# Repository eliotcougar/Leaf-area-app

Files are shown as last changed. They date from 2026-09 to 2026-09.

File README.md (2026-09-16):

# Leaf Area

Measure the projected leaf area inside a **6 cm² LI-6800 chamber opening** using an Android phone and a printed calibration mask.

The app uses markers around the opening to correct perspective and convert pixels to real area. Only leaf tissue inside the circle is counted. Processing works entirely on the device, without an internet connection or account.

## What you need

- An Android phone running Android 8.0 or newer.
- The [V2 cutout PDF](app/src/main/assets/LI6800-6cm2-marker-cutout-v2.pdf), printed on A4 paper.
- A flat, matte white backing, or a blue mat for contrasting with the leaf.

For a stiffer mask, attach the printout to a 3D-printed backing made from the [0.4 mm STEP model](app/src/main/assets/LI6800-6cm2-mask-v2-0.4mm.step). Both files can also be exported from the app’s menu.

## Measure a leaf

1. **Print at Actual size / 100%.** Disable “Fit to page” and check the printed 50 mm ruler. Cut out the mask and its circular opening, leaving the square markers intact.
2. Place the leaf flat on the backing with the mask on top. Keep the leaf and markers as close to the same plane as possible.
3. Open the camera and hold the phone nearly overhead. Keep the complete opening and at least four markers visible, distributed around the circle. Use even lighting and avoid glare.
4. Switch to **Calibration** to inspect the highlighted tissue. Select the matching backing color and adjust sensitivity until the selection follows the leaf. The area updates live in both views.
5. **Freeze** to inspect a reading, or tap the round **Save** button between Camera and Calibration to store it with an optional sample ID.

If markers disappear, the app keeps the last calibrated reading and labels it **Last reading**. Measurements resume when tracking returns. Saving a held reading stores its original calibrated image.

The screen stays awake during live measurement in both Camera and Calibration. Normal screen timeout resumes when you freeze the measurement or leave the app.

The camera button opens a list of available cameras and lenses. Your camera choice, matte color, and leaf sensitivity are remembered. The white or blue circle beside the flashlight shows the selected matte; change it in **Calibration**. Entries marked **automatic** let the phone choose the lens; choose an individual lens when you want to keep it fixed.

Use the flashlight button beside the camera button to toggle the selected camera’s light. It stays on in circle preview and turns off when you freeze or change cameras. Cameras without a flash show a disabled button.

For the LI-6800, enter the measured area in **cm²** as **S** under **Constants → Gas Exchange**. Keep the instrument’s chamber aperture set to 6 cm², and ensure the measured leaf region is the region enclosed by the chamber.

## Save and export

Open **Saved** to share a measurement as a ZIP containing:

- A CSV with the measured area.
- The source image, corrected circle image, and highlighted selection.
- A tissue mask and calibration metadata.

You can also measure an existing image using **Open photo**. Saved measurements stay on your device; export important records before uninstalling the app or clearing its data.

## Measurement limits

This app measures **projected area**, not the surface area of a curled leaf. Print scaling, a warped mask, lens distortion, uneven lighting, and shadows can affect the result. Inspect the selection before saving and check accuracy against known areas before using it in an experiment.

Detached dark shadows near the rim are filtered out, but shadows touching the leaf may still be counted. Very thin, gray tissue at the rim may be excluded. A physical measurement accuracy specification has not yet been established.

## Build from source

Open the project in Android Studio, using **JDK 21**, **Android SDK 37**, and **Build Tools 37.0.0**. Let Gradle sync, then run the app on a device or emulator.

Alternatively, with the JDK and Android SDK configured:

```sh
./gradlew :app:assembleDebug
```

On Windows, use `gradlew.bat` instead of `./gradlew`. The APK is written to `app/build/outputs/apk/debug/`.

For an optimized build, use `:app:assembleRelease`. Release builds enable code and resource shrinking; configure your own release signing key before distributing a build.

Built with Kotlin, Jetpack Compose, CameraX, and OpenCV. The template and mask generators are in [`tools/`](tools/).

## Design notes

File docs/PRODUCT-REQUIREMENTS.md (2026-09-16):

# LI-6800 product requirements

Read these requirements before changing measurements, templates, cameras, or
the measurement UI. They reflect the decisions through version 0.4.6; update
them when the product requirements change.

They take precedence over superseded proposals in
[MEASUREMENT-DESIGN.md](MEASUREMENT-DESIGN.md), including its proposed
mm²/coverage display and marker-loss presentation. The design document remains
the source for original-PDF findings and scientific validation requirements.
Release evidence belongs in versioned validation reports; the snapshot at this
revision is [VALIDATION-v046.md](VALIDATION-v046.md).

## Measurement and template

- Preserve `calibration_pad_pro.pdf` and `LI-6800-mask.pdf` unchanged. Print
  templates at Actual size / 100%, without resizing.
- Measure leaf tissue only within the 6.000 cm² (600 mm²) circular opening.
  Keep measured original-PDF geometry separate from that intended geometry;
  never silently rescale measurements to hide a mismatch.
- Require at least four markers around the opening for live calibration.
  Only V2 is calibrated; V1 support was removed in 0.4.0. Never reuse marker IDs
  across scales.
- The V2 PDF/STEP uses ten 8 mm markers, IDs 20-29, with two rear-center markers
  and forward side wings. Preserve the 111 × 68 × 0.4 mm backing, central front
  R20 arc, and 6 cm² opening.
- Use automatic segmentation with backing and sensitivity controls; the user
  excluded an add/erase workflow. Remember leaf sensitivity and selected matte
  across app restarts; default to white when no valid matte preference exists.
- Remove detached low-color rim shadows without shrinking the aperture.
  Preserve interior tissue and colored leaf tips.
- On marker loss, retain the last valid area, source, and timestamp with an
  explicit held-reading label; do not present a stale result as live.
- Keep demo workflows out of production and synthetic images in
  `androidTest/assets`, not `main/assets`. The menu exports PDF and STEP offline.

## Measurement screen

Keep the screen fixed and non-scrollable. Its two live display modes are a
full-screen camera and a square circle preview with sensitivity below. Both show
area at the top, in cm², without a mm²/coverage row.

The bottom row is Camera, a circular Save icon, and Calibration. Save is available
in both modes; do not duplicate it in the top overlay. Keep the same camera
session across display and tracking changes.

In Camera view, show the selected matte as a white or blue circle beside the
flashlight, matching its circle size. It is a status indicator; matte selection
remains in Calibration. Give the indicator an accessible selected-matte label.

While `InputMode.CAMERA` is active, keep the activity window awake in either
display mode, including marker loss. Clear `FLAG_KEEP_SCREEN_ON` when live mode
ends and on disposal; allow normal background timeout. Do not use a CPU wake lock.

## Camera selection and torch

The camera button lists exposed cameras/physical lenses and marks the remembered
selection. Distinguish automatic logical cameras from fixed physical lenses.
Keep failed choices selectable for retry, ignore error callbacks from old
sessions, and do not silently fall back on binding or runtime failure. Changing
cameras clears the previous calibration. Keep autofocus.

With the current CameraX 1.6.1 integration, preserve
`CameraChoice.configureOutputs` applying Camera2Interop physical IDs to both
Preview and ImageAnalysis builders. A selector's physical ID alone does not
establish the selected output. Verify resolved session/output IDs and
camera-service streams, not just the remembered picker key.

The flashlight toggle beside the picker uses the bound CameraX camera and
observed torch state. Disable it when flash is unavailable, keep torch on across
display changes, and turn it off when unbinding. Torch errors must not switch
cameras.

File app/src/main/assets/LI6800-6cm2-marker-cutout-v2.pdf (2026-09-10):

# Leaf area / 6 cm2

PRINT AT ACTUAL SIZE (100%) ON A4. Disable Fit to page.

Two identical cutouts. Cut on the outer line and remove the inner circle.

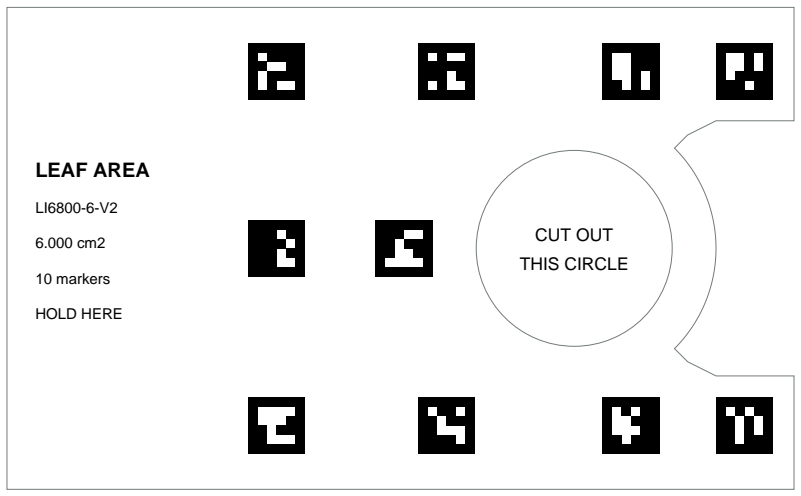
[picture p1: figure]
LEAF AREA; 10 markers; HOLD HERE; CUT OUT THIS CIRCLE
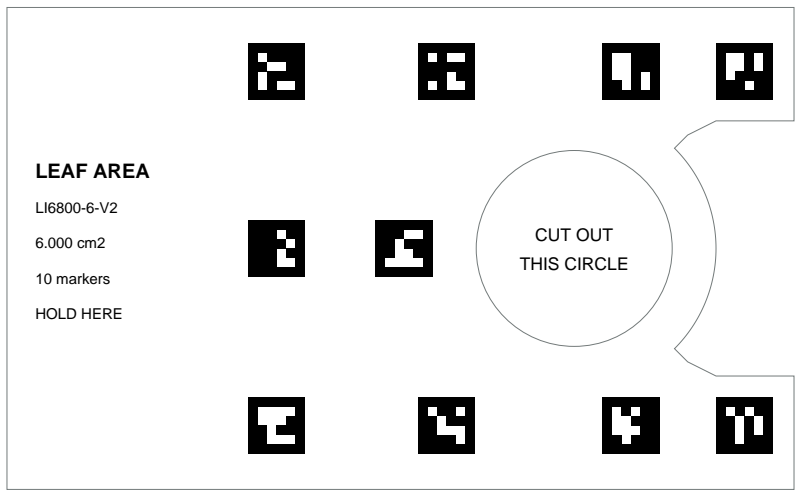
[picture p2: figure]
LEAF AREA; 10 markers; HOLD HERE; CUT OUT THIS CIRCLE

Check this line measures exactly 50 mm after printing

Place the leaf flat on a white backing, with this cutout on top.
Keep four or more well-spread markers visible. Use app 0.2.0 or newer.
Only leaf tissue in the circle is measured. Check the colored overlay before saving. Opening diameter: 27.6395 mm. The front tip retains the original 20 mm radius. External imaging aid. Keep the same leaf region registered for LI-6800 measurements.

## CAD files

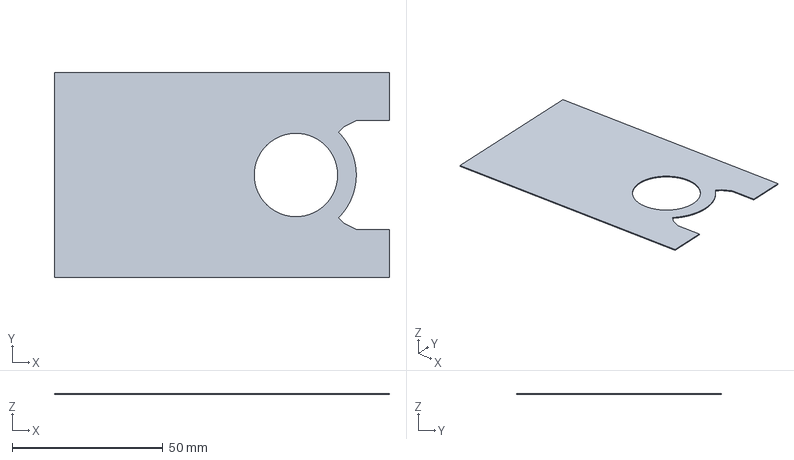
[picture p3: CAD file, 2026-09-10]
app/src/main/assets/LI6800-6cm2-mask-v2-0.4mm.step
111.0 x 68.0 x 0.4 mm

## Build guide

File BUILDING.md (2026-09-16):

# Android build environment on this PC

The root contains the LI-6800 Leaf Area app. Use `tools/build.ps1` to
build it; see `README.md` and `docs/VALIDATION-v046.md` for current behavior and checks.
The preparation results below remain a historical record of toolchain setup.

Inspected on 2026-09-10 at `E:\programming\li6800-area-app`.
The folder initially contained only the two reference PDFs and had no Git repository,
Android source, Gradle files, or app specification.

## Reference material

Both files have one A4 portrait page (595.28 x 841.89 PDF points).

| Input | Observed contents | SHA-256 |
| --- | --- | --- |
| `calibration_pad_pro.pdf` | Four PETIOLE PRO checkerboard calibration pads, numbers 5-8, with square markers and dashed cut outlines. | `9058EB1641443EC6F49095DF27F2E80B6DDB1639FD3E49665A59577CAB9C2116` |
| `LI-6800-mask.pdf` | Four mask outlines with circular openings near rounded ends. No extractable text or printed dimensions. | `8DBF324A2F4886218DC7214D2A3B5B6DE25125E46D51D00323A2044D38FB05D7` |

The user subsequently confirmed that the PDFs are true scale and must be printed
at Actual size / 100%, with no printer scaling. The application target is a 6 cm²
circle. Direct vector inspection found a small discrepancy in the original mask
drawing; see `docs/MEASUREMENT-DESIGN.md` and `docs/reference-geometry.json` for the
separate source dimensions and intended target. The original PDFs are unchanged.
The added real-world photo and proposed marker/measurement workflow are documented
in that design note. Legacy marker families/IDs have not been decoded.

## Installed tools and borrowed inputs

| Item | Verified local location/version |
| --- | --- |
| Java | `C:\Program Files\Android\Android Studio\jbr`, JetBrains JDK 21.0.10 |
| Android SDK | `C:\Users\eliot\AppData\Local\Android\Sdk` |
| SDK platforms | `platforms\android-36.1`, `platforms\android-37.0` (37 metadata has PreviewSdkInt=0) |
| Build tools | `build-tools\36.0.0`, `36.1.0`, `37.0.0` |
| ADB | SDK `platform-tools\adb.exe` |
| Emulator | SDK `emulator\emulator.exe`; no emulator launched for preparation |
| HTTPS curl | `C:\Users\eliot\AppData\Local\Microsoft\WinGet\Links\curl.exe`, curl-mingw 8.21.0 with LibreSSL 4.3.2 |
| Shared Gradle cache | `E:\programming\v2rayng\.gradle-user-home`, with Gradle 9.5.1 and 9.6.0 distributions |

The SDK's `cmdline-tools` directory is absent. Already installed SDK packages can
still build apps. If additional packages are required, use Android Studio's SDK
Manager or explicitly install command-line tools; do not assume `sdkmanager` is on PATH.

The Gradle wrapper was copied byte-for-byte from
`E:\programming\v2rayng\.worktrees\agp-modernization\V2rayNG`
(inspected HEAD `5f4949c56`). It pins Gradle 9.6.0 with its existing distribution
SHA-256. The smoke fixture uses the locally inspected AGP 9.4.0 / Kotlin 2.4.10
combination, compile/target SDK 37, build tools 37.0.0, and Java bytecode target 17.
These are local build inputs, not a claim about the latest available releases.

AGP in this fixture supplies built-in Kotlin. Its buildscript overrides the Kotlin
plugin dependency to the inspected 2.4.10 version. Do not additionally apply
`org.jetbrains.kotlin.android`. The root app uses the matching Compose compiler
plugin 2.4.10; the original smoke fixture does not use Compose.

Only the standard wrapper files were copied. The SDK/JDK and shared Gradle user
cache are referenced in place. Project caches use separate subdirectories here,
keyed by project path. Android user home and debug signing material remain local.
No v2rayNG VPN code, Go/NDK tooling, native AARs, product flavors, or signing keys
are needed by this Kotlin build fixture.

## Commands

Run from this folder in PowerShell. In Codex, every Gradle/build/test invocation
must use `sandbox_permissions: "require_escalated"`; do not use Windows UAC `RunAs`.
The script itself does not request elevation.

```powershell
# Compile Kotlin, process Android resources, dex, and package a debug smoke APK.
.\tools\smoke-build.ps1 -Offline

# Allow dependency downloads if an offline cache entry is unavailable.
.\tools\smoke-build.ps1

# Build the actual app:
.\tools\build.ps1
.\tools\build.ps1 -Tasks @(':app:assembleDebug', ':app:lintDebug')

# Signed, minified app release (same preserved signing identity):
.\tools\build.ps1 -Tasks @(':app:assembleRelease', ':app:lintRelease')
```

The smoke project lives under `tools\smoke-project`; its artifact is
`tools\smoke-project\app\build\outputs\apk\debug\app-debug.apk`.
It uses a separate `local.li6800.toolchainsmoke` package and provisional minSdk 24.
It is not the LI-6800 app. Running `tools/build.ps1` against the root builds
`app/build/outputs/apk/debug/app-debug.apk`, package `org.li6800.area`.

`tools/build.ps1` accepts `-ProjectPath`, `-JavaHome`, `-AndroidSdk`, and
`-GradleUserHome` overrides. It sets JAVA_HOME, ANDROID_HOME, ANDROID_SDK_ROOT,
ANDROID_USER_HOME, GRADLE_USER_HOME, and PATH together, restores them afterward,
uses `--no-daemon` and `--project-cache-dir`, writes timestamped logs under
`.build-logs`, and throws on Gradle failure. `--no-daemon` can still create a
single-use Gradle daemon that exits when the build finishes.

Use PowerShell array syntax for multiple tasks. Do not concatenate optional flags
into a command string or pass an empty ABI flag: this previously produced a stray
`-` task in another project on this PC.

## Machine-specific failure prevention

- A fresh project may have no ignored `local.properties`. Set both SDK environment
  variables in the same shell invocation as Gradle. A stale `sdk.dir` in an existing
  `local.properties` overrides them; inspect it before building.
- Sandbox cache/temp/subprocess failures can look like broken dependencies or
  compiler errors. Use the required unsandboxed execution from the beginning.
- Use the explicit curl-mingw path for HTTPS downloads; the Windows system curl is
  known to fail here. The installed alternative currently identifies LibreSSL,
  rather than Schannel. Never use `--insecure` as a workaround.
- Share dependency/distribution caches, not project state. Do not delete v2rayNG
  caches, modify its worktrees, or stop shared Gradle daemons during troubleshooting.
- Give builds time; inspect the current log and process command line before
  assuming a quiet process is stuck.
- Run at most one emulator on this PC. Inspect ADB devices and emulator/QEMU
  processes before launch, and establish ownership before stopping any existing one.
- The helper creates a project-local Android user home for future debug signing.
  Preserve the resulting key. For an update APK, compare signer certificate SHA-256
  with the previous artifact/device. Never silently switch to a v2rayNG or user key.

## Verification boundary

See the preparation result below for actual command outcomes. The smoke fixture
only checks the Android build toolchain. Runtime, camera permissions, calibration,
measurement accuracy, Compose dependencies, release signing, and device compatibility
are separate checks. Current app verification is recorded in `docs/VALIDATION-v046.md`.

Borrowed instruction sources: `E:\programming\v2rayng\AGENTS.md`,
`E:\programming\v2rayng\.tools\build-v2rayng-release-verify.ps1`, and the inspected
AGP modernization worktree's wrapper and Gradle configuration.

## Preparation result (2026-09-10)

- `tools/smoke-build.ps1 -Offline`: **passed**, 39 seconds, 34 tasks executed.
  Kotlin compilation, Android resource processing, dexing, and debug APK packaging
  succeeded without dependency downloads.
- Build log: `.build-logs\gradle-20260910-133039-740-5632.log`.
- Smoke APK: 933,835 bytes; SHA-256
  `595E7CBEDE38C37771CAE2DF938ED27A4A33CC92F8B36116C6D93E998524A9F6`.
- `apksigner verify --print-certs`: passed. Debug certificate SHA-256
  `597b4d2452fab4dec76811d4a4c6203ddd732ea8605ad05a1ff54581209766a1`.
  The new key is `.android-user-home\debug.keystore`; keep it ignored and preserve it.
- Both PowerShell scripts parsed successfully. All four copied wrapper files match
  the source SHA-256. Both PDF hashes still match their initial values.
- Final host process inspection found no Java/Gradle, Git, or emulator/QEMU process.
  The ADB device list was empty. The ADB server started by the inventory check is
  intentionally left available on port 5037; no APK was installed.
- **Not run during preparation:** emulator/physical-device execution, Compose
  compilation, camera or measurement validation, and production release signing.

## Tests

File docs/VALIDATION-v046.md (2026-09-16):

# Version 0.4.6 — remember and display the selected matte

Validated 2026-09-16.

The selected matte is saved in measurement preferences and restored on app
startup, with white as the fallback for missing or invalid values. The camera
screen displays a white or blue 40 dp circle beside the flashlight, inside a
48 dp layout box. It has an accessible selected-matte label; selection remains
in Calibration.

## Checks

- Signed release assembly and lint passed in 1m 40s; zero lint errors,
  30 warnings. Log: `.build-logs/gradle-20260916-124952-738-22916.log`.
- Installed the minified release on Pixel_6a API 33 x86_64. The initial matte
  without a saved preference was white.
- Selected blue in Calibration, returned to Camera, force-stopped the app and
  relaunched it: the matte and indicator remained blue. Repeated for white,
  with the same successful result.
- UI-tree checks confirmed the selected-matte labels and non-clickable indicator.
  Visual inspection of both restarted screenshots confirmed matching flashlight
  circle size and no clipping or overlap.
- Evidence: `.build-logs/qa/matte-v046.txt`, `v046-restarted-blue.png`,
  `v046-restarted-white.png`, and their XML snapshots.
- Runtime logs showed one camera binding per process, with no extra binding
  when changing matte or display mode, and no LeafArea or AndroidRuntime errors.
  Log: `.build-logs/qa/runtime-v046.txt`.
- No full regression suite was rerun or new repository tests added for this
  small settings/UI change. Physical-device behavior was not tested.

## Release artifact

`output/apk/LI6800-Area-0.4.6-release-universal.apk`, versionCode 10,
149,606,041 bytes; minified, resource-shrunk, non-debuggable, four ABIs.

- SHA-256: `edebd48ff66f0c7a24b837af2fe37c2c460ce590f2323bbb7094ba7b3361b40d`.
- Signature and 16 KB ZIP alignment passed. Signer matches 0.4.5:
  `597b4d2452fab4dec76811d4a4c6203ddd732ea8605ad05a1ff54581209766a1`.
- Assets are unchanged V2 PDF/STEP/JSON and baseline profiles. No demo or V1 assets.
- Delivered to the local Dropbox root with matching SHA-256; cloud sync unverified.

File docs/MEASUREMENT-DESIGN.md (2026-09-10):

# LI-6800 leaf area measurement: research and design

Research date: 2026-09-10. This document separates manufacturer information,
observed local inputs, and proposed implementation. No measurement app or new
printable template was created during this research.

## Measurement contract

The app measures the **one-sided projected area of leaf tissue within a circular
6.000 cm² opening**, equivalent to 600 mm². Leaf portions outside the opening,
paper, background, and holes where tissue is absent contribute zero. Yellow,
brown, or necrotic tissue still counts as leaf tissue; this is not a greenness meter.
For a flat leaf this is the planar area. It is not a reconstruction of the surface
area of a curled leaf, and should not double the result for the two leaf surfaces.

The user confirmed true-scale PDF printing at 100%, with no printer resizing, and
clarified that the intended opening is **6 cm²**. The new mask definition should
therefore use radius `sqrt(600/pi) = 13.819765979 mm`, diameter `27.639531958 mm`.
The target is not 5.94 cm².

## LI-COR fluorometer head

The relevant attachment is the **6800-01A Multiphase Flash Fluorometer**, a chamber
and light source for gas exchange and chlorophyll-a fluorescence over the same
leaf area. It uses PAM measurement and supports multiphase saturation flashes.
Its interchangeable circular apertures are nominally 6 cm² and 2 cm².

| Manufacturer specification | Value |
| --- | --- |
| Measuring/red light peak | 625 nm |
| Blue light peak | 475 nm |
| Far-red peak | 735 nm |
| Total actinic light, at 25 °C | 0-3,000 µmol m⁻² s⁻¹ |
| Saturating flash, at 25 °C | Up to 16,000 µmol m⁻² s⁻¹ |
| Attachment size and mass | 16.6 × 11.5 × 13.6 cm; 0.86 kg |

Source: [LI-COR fluorometer product specifications](https://www.licor.com/products/photosynthesis/LI-6800/fluorometer).

Upper and lower apertures must match. The instrument recognizes the chamber but
does not identify the installed aperture automatically: the operator selects the
aperture in Chamber Setup. Changing only leaf area is not a substitute for choosing
the correct hardware aperture. [LI-COR installation instructions](https://bio.licor.com/env/support/LI-6800/topics/chamber-fluorometer-installation.html).

LI-COR lists 6800-50 for the 6 cm² aperture and 6800-51 for 2 cm², with two apertures
required for operation. These identify hardware sizes, not dimensions inferred
from a photograph. [LI-COR ordering information](https://www.licor.com/products/photosynthesis/LI-6800/ordering).

Under **Constants > Gas Exchange**, `S` is the area of the chamber occupied by the
leaf, in cm². LI-COR explicitly uses this area when calculating assimilation and
provides an onboard area calculator. Our app should supply this occupied area,
which can be smaller than 6 cm², while the hardware aperture setting stays at
6 cm². [LI-COR leaf chamber controls](https://www.licor.com/support/LI-6800/topics/leaf-measurement-controls.html).

Design consequence: report mm², cm², and percentage of the opening. The first
version can present a value to enter as `S`; connection to the LI-6800 is a separate
feature. Photograph the same leaf region enclosed during gas exchange. Use physical
registration marks or a documented placement procedure so repositioning the mask
does not select a different patch. Paper measurement masks should be treated as
external imaging aids, not assumed to be validated chamber inserts.

## Local PDF and photograph findings

The supplied `2026-09-10 12.40.27.jpg` shows a white mask with a manually cut circular
opening beside a separate PETIOLE PRO pad No. 5, on a wood-grain surface. There is
no leaf in the photograph and there are no markers on the mask. The image helps
establish physical layout; it provides no evidence of leaf segmentation accuracy.

Direct vector inspection of `LI-6800-mask.pdf` found four approximately 100 × 40 mm
outlines, each with a circle bounded by approximately 27.4997 × 27.5001 mm. The
ideal ellipse area computed from those bounds is 5.93953 cm². This is a finding
about the source drawing, not a measurement of the LI-COR hardware. LI-COR's
nominal 6 cm² specification does not establish the precise bore diameter.

The original PDF remains unchanged. A future corrected template should explicitly
encode the user's 600 mm² target and known marker coordinates. Do not silently
scale a 27.5 mm opening to 6 cm² in the software: that would also rescale the leaf
measurement. A full opening on the corrected template should return 600 mm².

`calibration_pad_pro.pdf` contains four pads (5-8). Pad No. 5 has 5 mm checkerboard
squares in the PDF and eight 5 × 5 mm embedded image tiles at marker locations.
The exact legacy marker family, IDs, and black-border dimensions were not decoded;
the embedded image bounds alone do not identify the marker dictionary.

The reproducible mask extraction is in `tools/inspect-reference-geometry.py`;
`docs/reference-geometry.json` records source hashes, original vector dimensions,
and the separate 6 cm² application target. The original files were only read.

## Libraries and precedent

| Candidate | Role and assessment |
| --- | --- |
| CameraX | Android camera preview and analysis frames; use lifecycle binding and latest-frame backpressure. |
| OpenCV ArUco + a custom Board | Preferred marker detector: identified corners and a board of known corner coordinates. |
| OpenCV homography and image processing | Rectify the paper plane, segment tissue, and intersect it with the circle. |
| AprilTag 3 | Viable alternate fiducial system if trials favor it; direct native integration adds work. |
| ARCore Augmented Images | Designed for tracking reference images in AR. It is not needed for this planar measurement pipeline. |

CameraX provides CPU-accessible analysis frames and `STRATEGY_KEEP_ONLY_LATEST` to
avoid a backlog; the analyzer must close every `ImageProxy`.
[CameraX image analysis](https://developer.android.com/media/camera/camerax/analyze?hl=en).

OpenCV's modern marker API is `ArucoDetector` in `objdetect`, with a Java API
callable from Kotlin. Its Android distribution has a Maven Central installation
route. Select and pin an actual artifact during implementation, and verify its
Java API and packaged ABIs in an Android build before claiming integration.
[Marker tutorial](https://docs.opencv.org/4.13.0/d5/dae/tutorial_aruco_detection.html),
[Java API](https://docs.opencv.org/4.13.0/javadoc/org/opencv/objdetect/ArucoDetector.html),
[Android distribution options](https://opencv.org/opencv4android-usage-models/).

A Board defines marker IDs and their known corner coordinates; it need not cover
the opening with a chessboard. [OpenCV boards](https://docs.opencv.org/4.13.0/db/da9/tutorial_aruco_board_detection.html).
AprilTag is another established visual fiducial implementation.
[AprilRobotics source](https://github.com/AprilRobotics/apriltag).
ARCore reference images require sufficient image features and at least 25% frame
coverage for initial detection; a custom small-marker board is a more direct fit
here. This preference is our design assessment, not a measured performance comparison.
[ARCore Augmented Images](https://developers.google.com/ar/develop/augmented-images).

Petiole's current documentation explicitly describes eight ArUco markers, known
print size, and keeping the leaf and calibration plate in the same plane. That
confirms the calibration workflow exists. Its current documentation does not
prove the internals of the older app associated with the supplied 2021 PDF. No
legacy APK was downloaded or decompiled, and its segmentation or claimed accuracy
has not been reproduced.
[Petiole calibration workflow](https://petiole.pro/blog/leaf-area-measurement/do-i-need-calibration-plate-petiole-pro/),
[2021 Petiole pad instructions](https://www.petiolepro.com/blog/how-can-i-get-the-calibration-pad-for-petiole-app/).

## Proposed printable marker layout

Print at least four **distinct, identified markers around the opening**, with their
corners stored in millimetres in a versioned template definition. Six or eight can
add redundancy if physical space permits; a result still requires at least four
well-distributed visible markers, following the user's requirement. Use all their
corners, not just four marker centers. Markers clustered on one side should not
qualify as a well-supported measurement of the opening.

The original rounded end has a 20 mm outside radius. With the target aperture,
only about **6.18 mm of radial paper** remains. Large square markers plus white
clearance will not fit freely around that ring. Prototype compact rotated markers
on this exact outline first; if they cannot be reliably read at the camera's
working distance, an enlarged imaging collar is a separate template design choice.
Do not enlarge the opening or place markers over it to make them fit.

A known ArUco dictionary such as `DICT_4X4_50` is a reasonable initial trial for
small markers. Print clean black borders with white clearance and unique IDs.
Keep the aperture and marker positions in one generated coordinate system. Add a
scale bar and template version outside the measurement opening. Users print at
Actual size / 100%, with Fit to page disabled, as requested. A ruler check verifies
printer output rather than changing the intended true-scale workflow.

## Proposed live measurement pipeline

1. Acquire a frame on a background analyzer. Handle rotation, cropping, and image
   plane strides correctly; keep preview overlay coordinates consistent with analysis.
2. Detect expected marker IDs and refine their corners. Require at least four
   markers spread around the aperture and sufficient sharpness and pixel coverage.
3. Estimate the image-to-template planar homography from known marker corner
   coordinates, rejecting inconsistent points. Use lens-distortion correction where
   needed and validated for the camera stream. A homography does not itself model
   radial lens distortion or a bent sheet.
4. Rectify the aperture region to a metric grid. For example, at `q` pixels/mm,
   each rectified pixel represents `1/q²` mm². This is a projective calibration,
   not a single pixels/mm ratio applied everywhere in a tilted camera image.
5. Segment leaf tissue inside the known circle. Begin with a controlled matte,
   contrasting backing and automatic color-based segmentation with backing and
   sensitivity controls. The user excluded add/erase editing. Green-only thresholding is
   insufficient for yellow/brown leaves, and dark pixels alone are not leaf tissue.
6. Compute `area_mm² = sum(leaf_mask AND aperture_mask) / q²`, retaining holes.
   At edges, use subpixel coverage or quantify rasterization error. Convert to cm²
   by dividing by 100; coverage percent is `100 * area_mm² / 600`.
7. Overlay accepted tissue and the opening boundary. Permit saving only while
   calibration and segmentation quality are valid. Losing markers must invalidate
   the live result rather than silently reusing stale scale. Temporal smoothing can
   stabilize accepted results but must not imply higher measurement accuracy.

The perspective transformation is supported by the planar geometry described in
[OpenCV's homography tutorial](https://docs.opencv.org/4.x/d9/dab/tutorial_homography.html).
The segmentation choices, quality gates, and metric integration above are our
proposed implementation, not a claim about Petiole's source code.

The leaf and marker plane need to be nearly coincident. A leaf sagging below the
opening or curled above it introduces parallax that paper markers cannot correct.
Use a flat backing and a near-normal camera view. The wood grain in the supplied
photo is useful for layout inspection but is not a controlled segmentation background.
Cut accuracy also matters: the app should check for paper intruding into the intended
circle and reject a badly cut mask rather than count hidden tissue.

## Validation before reporting scientific accuracy

- Analytic fixtures: empty circle = 0; full circle = 600 mm²; half circle = 300 mm²;
  known polygons crossing the circle; interior holes and separate leaf fragments.
- Geometry: varying distance, perspective, image rotation, missing markers, wrong
  template IDs, partial occlusion, blurred frames, curved paper, and lens changes.
- Segmentation: green/yellow/brown leaves, reflections, shadows, thin tips, insect
  holes, and backgrounds that resemble the leaf. Check the overlay against a manual
  reference; do not fill true holes during morphological cleanup.
- Physical standards: measured cutouts of known area spanning the 0-600 mm² range,
  repeated on multiple prints, lighting conditions, and phone cameras. Use a ruler
  or independent area standard; the template cannot verify its own print accuracy.
- Preserve sample ID, area, coverage, template version, calibration residuals,
  available image metadata, analyzed frame, segmentation mask, and threshold settings.
- Report absolute error in mm², bias, repeatability, and failure rates. Set numeric
  acceptance thresholds from these trials; neither library availability nor a smooth
  live number demonstrates scientific accuracy.

The research above informed the implemented first iteration. See `VALIDATION-v1.md`
for build and emulator evidence. Physical accuracy trials remain outstanding.

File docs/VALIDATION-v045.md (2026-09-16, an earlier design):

# Version 0.4.5 — keep live measurements awake

Validated 2026-09-11.

The activity sets `FLAG_KEEP_SCREEN_ON` while `InputMode.CAMERA` is active,
independently of Camera/Calibration display mode and marker tracking. A Compose
disposal effect clears the flag when live capture ends or the screen is disposed.
Android stops honoring the flag when the activity is backgrounded. No permission
or CPU wake lock is needed.

## Checks

- Final signed release assembly and lint passed in 1m 14s; zero lint errors,
  30 warnings. Log: `.build-logs/gradle-20260911-130139-803-16732.log`.
- Installed the minified release on Pixel_6a API 33 x86_64, with screen timeout
  temporarily set to 15 seconds and charging stay-awake disabled.
- Camera and Calibration remained awake without touches after 20 seconds each,
  while searching for markers. Window service identified this app as the window
  keeping the display awake.
- Open photo stops live capture; canceling returns to the stopped screen with
  the Live button visible. Its keep-awake window cleared. The emulator was still
  awake at the first 20-second check, then a longer check confirmed Asleep with
  no keep-awake window.
- Resuming Live restored the keep-awake window. Background timeout was checked
  separately. Original emulator timeout/charging settings were restored.
- Evidence: `.build-logs/qa/v045-final-camera.txt`, `v045-final-calibration.txt`,
  `v045-final-stopped-full-power.txt`, and `v045-final-background.txt`.
- An initial view-property implementation failed the stopped-mode cleanup check
  and was replaced with explicit window flag handling before final handoff.
  The final APK checksum below identifies the corrected build.
- No new repository tests were added or full regression suite rerun for this
  small patch. Physical-device behavior was not tested.

Reference: [Android screen-awake behavior](https://developer.android.com/develop/background-work/background-tasks/awake/screen-on).

## Release artifact

`output/apk/LI6800-Area-0.4.5-release-universal.apk`, versionCode 9,
149,605,629 bytes; minified, resource-shrunk, non-debuggable, four ABIs.

- SHA-256: `d5174ed4a26ef9fd777df7db4c3f0bc5e8b829e8798d96754e883a08c7686f6e`.
- Signature and 16 KB ZIP alignment passed. Signer matches 0.4.4:
  `597b4d2452fab4dec76811d4a4c6203ddd732ea8605ad05a1ff54581209766a1`.
- Assets are unchanged V2 PDF/STEP/JSON and baseline profiles. No demo or V1 assets.
- Delivered to the local Dropbox root with matching SHA-256; cloud sync unverified.

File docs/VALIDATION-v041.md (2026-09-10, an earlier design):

# Version 0.4.1 — explicit camera selection

Validated 2026-09-10 in `E:\programming\li6800-area-app`.

## Behavior and cause addressed

The 0.4.0 binding-error handler removed the failed choice and automatically bound
another camera. A missing selected ID also resolved to the first camera. Both
paths could undo an explicit selection. These paths are removed: failure retains
the requested key, reports Camera unavailable, and leaves the picker accessible.
The user's exact hardware failure was not reproduced on their physical phone.

The button now opens a radio-button list with facing, camera/lens ID, focal length
when available, and an automatic label for logical multi-lens cameras. Physical
lenses remain listed even if their ID is also exposed as a direct logical camera;
those selectors have different behavior. The chosen key is saved in private
preferences and used after activity recreation and process restarts.

CameraX state errors are handled without fallback, and obsolete session callbacks
cannot stop a newer camera. A successful switch starts fresh calibration. Camera
and Circle & sensitivity display changes retain the selected camera and session.

## Checks

- Final build: `tools/build.ps1` with assembleRelease, assembleDebug,
  assembleDebugAndroidTest, testDebugUnitTest, and lintRelease. Passed in 1m 10s.
  Log: `.build-logs/gradle-20260910-191406-916-25084.log`.
- JVM: two tests passed. Release lint: zero errors, 30 warnings.
- Direct instrumentation: **OK (10 tests)** on Pixel_6a API 33 x86_64.
  `.build-logs/qa/instrumentation-v041.txt`.
- Regression coverage includes opening the list without switching, selected radio
  state, explicit front selection, display changes, activity recreation, missing
  camera failure without fallback, recovery through the same picker, preference
  restoration, and ignoring old-session errors. Existing measurement tests pass.
- One initial UI run was interrupted by the emulator's unrelated wireless-debugging
  system dialog. It was canceled, then the complete suite passed.
- Installed the signed minified release over the previous package. The picker
  showed rear camera 0, automatic front camera 1, and physical front lenses 3/4.
- Selected front lens 3 (key `1/3`), force-stopped and relaunched the release.
  Logs confirm `Bound selected camera 1/3` in both processes, and the refreshed UI
  tree confirms Front lens 3 remained checked. No unexpected switch was observed.
- Final release LeafArea/AndroidRuntime error log is empty. This is separate from
  the deliberate missing-camera error exercised by the debug instrumentation test.
- Evidence: `.build-logs/qa/v041-release-picker.png`, `v041-release-restored.xml`,
  `v041-release-binding.txt`, and `runtime-v041.txt`.

## Release artifact

`output/apk/LI6800-Area-0.4.1-release-universal.apk`, 149,585,897 bytes.

- SHA-256: `eecac05776cfed4c5d401039cfad517b9fdaa54640d92d2bc474c99b175b83df`.
- Signature and 16 KB ZIP alignment verification passed. Certificate unchanged:
  `597b4d2452fab4dec76811d4a4c6203ddd732ea8605ad05a1ff54581209766a1`.
- Minified/resource-shrunk, non-debuggable release, versionCode 5; ARM64, ARMv7,
  x86_64 and x86. The preserved certificate is named Android Debug, as in V4.
- Asset audit confirms only V2 JSON/PDF/STEP and generated baseline profiles.
  No demo assets or V1 template data. Generated deliverables remain ignored by Git.
- Copied to `C:\Users\eliot\Dropbox\LI6800-Area-0.4.1-release-universal.apk`;
  copied SHA-256 verified. Cloud sync was not checked.

## Limits

The emulator exposes a simulated logical/physical multi-camera configuration;
real phone lens availability, HAL behavior, and optical performance need physical
validation. Entries marked automatic still intentionally allow device lens choice.
An explicit physical selector requests that lens; unsupported configurations are
reported rather than replaced. Previous segmentation/accuracy limits still apply.

API references: [physical camera selection](https://developer.android.com/reference/androidx/camera/core/CameraSelector.Builder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)
and [physical camera enumeration](https://developer.android.com/reference/androidx/camera/core/CameraInfo#getPhysicalCameraInfos()).

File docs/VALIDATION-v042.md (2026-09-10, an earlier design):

# Version 0.4.2 — flashlight control

Validated 2026-09-10. Camera-selection and measurement behavior from
[0.4.1](VALIDATION-v041.md) is retained.

## Behavior

- A flashlight toggle sits immediately beside the camera picker in Camera view.
  Its highlighted state follows CameraX's reported torch state.
- The button is disabled when the selected camera has no flash or while a torch
  request is pending. A failed request reports a short message without changing
  the selected camera or resetting calibration.
- Circle preview retains the camera and light. Unbinding for a camera switch,
  freeze, or leaving live capture turns the light off. Torch state is not saved.
- Observers are removed on disposal; completions from old controls are ignored.

## Verification

- Release/debug APK assembly, Android test APK assembly, two JVM tests, and
  release lint passed. Lint: zero errors, 30 warnings.
  Build log: `.build-logs/gradle-20260910-192722-077-8068.log` (1m 24s).
- Pixel_6a API 33 x86_64 instrumentation: **OK (10 tests)**.
  The rear camera has no flash; its disabled toggle was checked along with
  existing calibration, layout, camera selection and persistence regressions.
  Log: `.build-logs/qa/instrumentation-v042.txt`.
- Installed and exercised the signed minified release. The emulator's front
  camera supports a simulated torch: the toggle changed to ON, stayed ON through
  Circle & sensitivity and back, and changed to OFF on request.
- Switched from front camera with torch ON to rear camera (disabled toggle),
  then back to front: torch was OFF. Binding logs show only the initial binding
  and the two deliberate camera switches, with no rebind from torch/display changes.
- Inspected release screenshot: flashlight and lens picker are adjacent below
  the top overlay, with a yellow background for torch ON.
  Evidence: `.build-logs/qa/v042-flashlight-on.png`, `v042-flashlight-off.xml`,
  `v042-flashlight-retained.xml`, `v042-switch-resets-torch.xml`, and
  `torch-binding-v042.txt`.
- Release LeafArea/AndroidRuntime error-log query returned no entries. The
  task-owned emulator was shut down after validation.

Physical illumination and phone-specific flash behavior were not tested. Freeze
shutdown uses the same unbind cleanup; it was not separately exercised with the
simulated torch ON. Torch-request failure handling was reviewed, not fault-injected.

## Delivered APK

`output/apk/LI6800-Area-0.4.2-release-universal.apk`, versionCode 6,
149,605,069 bytes. R8 minified, resource-shrunk, non-debuggable; ARM64, ARMv7,
x86 and x86_64. Signature and 16 KB ZIP alignment checks passed.

- SHA-256: `f447e5d60850a27a60389034a002f2081eebe17085c66f11948da769bc3be398`.
- Signer matches 0.4.1:
  `597b4d2452fab4dec76811d4a4c6203ddd732ea8605ad05a1ff54581209766a1`.
- Assets contain only the unchanged V2 PDF/STEP/JSON and generated baseline
  profiles; no demo assets or V1 template data.
- Copied to `C:\Users\eliot\Dropbox\LI6800-Area-0.4.2-release-universal.apk`;
  source/copy SHA-256 verified. Cloud sync was not checked.

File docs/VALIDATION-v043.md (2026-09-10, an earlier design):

# Version 0.4.3 — physical lens routing

Validated 2026-09-10. The user reported a Pixel 9 Pro briefly changing lenses,
then snapping back while the selected picker entry remained unchanged.

## Cause and correction

The app set `CameraSelector.physicalCameraId`, but CameraX 1.6.1's
`LifecycleCameraProviderImpl.bindToLifecycleInternal` does not copy that ID to
the use cases in the single-camera binding path. Its multi-camera path does.
The saved choice therefore did not ensure physical routing of preview/analysis.

`CameraChoice.configureOutputs` now applies `Camera2Interop.Extender` physical
IDs to both Preview and ImageAnalysis before building them. Automatic entries
leave the ID unset. Autofocus remains enabled. The selected key, failure handling,
torch behavior, and calibration reset rules are preserved.

Inspected the exact pinned library's
[1.6.1 sources](https://dl.google.com/dl/android/maven2/androidx/camera/camera-lifecycle/1.6.1/camera-lifecycle-1.6.1-sources.jar)
and the documented
[Camera2 physical output API](https://developer.android.com/reference/androidx/camera/camera2/interop/Camera2Interop.Extender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).
Source copies and inspection extracts are ignored under `.build-logs/`.

## Checks

- Release/debug assembly, test APK assembly, two JVM tests and release lint passed.
  Final application build: `.build-logs/gradle-20260910-194246-609-15292.log`,
  1m 12s. Lint: zero errors, 30 warnings. The initial lint run required replacing
  a Kotlin `check` with an explicit API-level guard recognized by lint.
- Existing 10 instrumentation tests passed on Pixel_6a API 33 x86_64. The new
  physical-output test initially read only per-output IDs. CameraX's graph provider
  gives the session-wide interop ID precedence, so the test was corrected to
  inspect the resolved ID using the same rule.
- Corrected physical binding test: **OK (1 test)**, 2.402s, using the final debug
  APK. It binds physical 3, physical 4 and automatic, requires three live analysis
  frames from each, and checks both bound streams' resolved physical IDs:
  `1/3 → [3,3]`, `1/4 → [4,4]`, `1 → [null,null]`.
  Logs: `.build-logs/qa/physical-binding-v043.txt` and `physical-outputs-v043.txt`.
- Signed minified release installed. Selected Front lens 3 through the picker.
  Android `dumpsys media.camera` showed **Physical camera id: 3** on both output
  streams, with 537 frames produced on each, and active physical ID `3`.
- Camera/circle mode changes did not cause a rebind. Force-stop/relaunch restored
  `1/3`; camera service again reported physical ID 3 on both streams, with 1,352
  frames each. Logs contained only intended bindings and no LeafArea/runtime errors.
  Evidence: `.build-logs/qa/v043-release-camera.txt`,
  `v043-release-restarted-camera.txt`, `v043-fixed-lens.xml`, `runtime-v043.txt`.
- The task-owned emulator was shut down after verification.

The Pixel 9 Pro's optical close-focus behavior was not tested on physical hardware.
The correction is verified through the emulator camera service and live frames;
this does not establish physical-phone autofocus performance or measurement accuracy.

## Delivered release

`output/apk/LI6800-Area-0.4.3-release-universal.apk`, versionCode 7,
149,605,069 bytes. R8 minified, resource-shrunk, non-debuggable, four ABIs.

- SHA-256: `bec95c056055464aa152d94205c594eb228390592ffa6f7a2a54381c81c3a2ca`.
- Signature and 16 KB ZIP alignment checks passed. Certificate matches 0.4.2:
  `597b4d2452fab4dec76811d4a4c6203ddd732ea8605ad05a1ff54581209766a1`.
- Assets contain unchanged V2 PDF/STEP/JSON and baseline profiles; no demo or V1
  assets. Reference PDFs and mask geometry were not modified.
- Copied to `C:\Users\eliot\Dropbox\LI6800-Area-0.4.3-release-universal.apk`;
  source and copied hashes match. Cloud synchronization was not checked.

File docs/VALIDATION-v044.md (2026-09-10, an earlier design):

# Version 0.4.4 — bottom controls

Validated 2026-09-10.

The circle/sensitivity mode is now labeled **Calibration**, including help and
the public README. Save moved from the top overlay to a 52 dp circular icon
between the equally sized Camera and Calibration buttons. It remains available
in both modes and preserves the existing save dialog and valid-reading checks.

## Verification

- Release/debug/test APK assembly and release lint passed (1m 14s).
  Log: `.build-logs/gradle-20260910-195951-661-19060.log`.
  Lint: zero errors, 30 warnings.
- Existing `MeasurementScreenTest` passed on Pixel_6a API 33 x86_64 (23.37s).
  This covers fixed layout, held readings, both live modes and camera selection.
  No new tests were added for this layout change; the full suite was not rerun.
- Visually inspected screenshots with a valid held reading in both modes. Save
  is centered between the two mode buttons; Calibration fits without clipping.
  Screenshots: `.build-logs/qa/v044-camera.png` and `v044-circle-sensitivity.png`.
- Installed and launched the signed minified release; its UI tree confirms the
  new bottom row and no top Save action. No LeafArea/runtime errors appeared.
  Evidence: `.build-logs/qa/v044-release.xml` and `runtime-v044.txt`.
- The emulator was shut down afterward. Physical-device checks were not run.

## Release

`output/apk/LI6800-Area-0.4.4-release-universal.apk`, versionCode 8,
149,605,629 bytes. Minified, resource-shrunk, non-debuggable; four ABIs.
Signature and 16 KB ZIP alignment verification passed.

- SHA-256: `8b5256dfcdb918057ff20f58f9be63d4d0a9728b34f8953d9e7b020557f7bd1f`.
- Signer matches 0.4.3:
  `597b4d2452fab4dec76811d4a4c6203ddd732ea8605ad05a1ff54581209766a1`.
- Assets contain only unchanged V2 PDF/STEP/JSON and baseline profiles, with no
  demo or V1 assets.
- Copied to `C:\Users\eliot\Dropbox\LI6800-Area-0.4.4-release-universal.apk`;
  source and copy hashes match. Cloud sync was not checked.

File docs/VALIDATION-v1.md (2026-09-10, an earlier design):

# First iteration validation - 2026-09-10

Workspace: `E:\programming\li6800-area-app`. Package `org.li6800.area`, version
`0.1.0` (1), Android 8.0/API 26 or newer. This is a project-debug-signed evaluation
APK. The user excluded add/erase editing; the final app uses automatic segmentation
with backing and sensitivity controls.

## Delivered artifacts

| Artifact | Bytes | SHA-256 |
| --- | ---: | --- |
| `output/apk/LI6800-Area-0.1.0-debug-universal.apk` | 161325893 | `8d0e180178d96a24475f25a6fc01606fc6b2304fde4be98f2b53489ebd6a0178` |
| `output/pdf/LI6800-6cm2-marker-cutout-v1.pdf` | 6167 | `45b124f366d46935ccfebe9235ab7bfaf7ccadb30064a3c0497c9e9c3a6293ab` |

The APK includes ARM64, ARMv7, x86, and x86_64. `apksigner verify --verbose
--print-certs` passed with v2 signing. Certificate SHA-256:
`597b4d2452fab4dec76811d4a4c6203ddd732ea8605ad05a1ff54581209766a1`.
`zipalign -c -P 16 -v 4` passed. Every ARM64 ELF LOAD segment has 16384-byte
alignment; this is a packaging check, not execution on a 16 KB-page device.

The PDF has one A4 page with two identical templates. Independent PDF vector
read-back measured both opening bounds as 27.639539 mm in each axis (rounding in
PDF serialization); the source formula is `2 * sqrt(600/pi)` mm. The 50 mm ruler
was also verified from the PDF. Rendering and visual inspection passed; OpenCV
decoded all 12 markers, with IDs 10-15 appearing twice. The six markers on each
cutout are 10 mm squares. The original front 90-degree arc of radius 20 mm stays
in place while the sides widen to 68 mm. This arc is the implementation's
interpretation of the protected front of the curved tip.

The PDF embedded in the APK, the desktop output, and the PDF exported through
Android's Create Document picker have identical bytes. Print at Actual size/100%
and check the ruler independently; software read-back cannot verify a printer.

## Build and automated checks

Command: `tools/build.ps1 -Tasks @(':app:assembleDebug',
':app:assembleDebugAndroidTest', ':app:testDebugUnitTest', ':app:lintDebug')`.
Passed in 58 seconds. Log: `.build-logs/gradle-20260910-143226-107-21316.log`.
The helper uses the installed Android Studio JDK 21, SDK 37, shared v2rayNG Gradle
dependency cache, and this project's own caches and signing key.

- Two JVM tests passed: analytic empty/full/half area, exclusion outside the
  aperture, and exclusion of a known central circular hole.
- Lint: 0 errors, 10 warnings. Five dependency-version suggestions, four KTX style
  suggestions, and one pre-Android-12 backup configuration suggestion. Backup is
  disabled in the manifest; Android 12+ extraction rules exclude measurement files.
- Three Android instrumentation tests passed through the direct runner, with
  explicit `OK (3 tests)`: native ArUco detection and measurement, rejection with
  only three markers, and saved archive read-back including CSV formula handling.

Earlier, the Gradle connected-test task reported BUILD SUCCESSFUL despite an
emulator install failure during boot. That run was not counted. The final APK and
test APK installed successfully with `adb install --no-streaming`, then the direct
instrumentation runner passed. Evidence: `.build-logs/qa/instrumentation-final.txt`.

## Numerical checks on Android

These are synthetic images processed by the app's actual OpenCV implementation
on the x86_64 emulator, using white backing and sensitivity 0.5. They establish
software behavior, not an accuracy specification for real leaves.

| Fixture | Expected (mm²) | Measured (mm²) |
| --- | ---: | ---: |
| Empty | 0 | 0 |
| Half circle | 300 | 299.55625 |
| Full circle | 600 | 599.14 |
| Leaf shape with hole | 415.5, fixture raster reference | 415.3575 |
| Half circle under perspective | 300 | 299.43125 |
| Yellow full coverage | 600 | 599.59125 |
| Only three markers | No result | No result |

All six valid fixtures detected six markers. Homography RMS residual was
0.006641 mm for the flat fixtures and 0.016226 mm for perspective. This residual
measures marker fit only, and must not be interpreted as leaf area accuracy.

## Emulator UI checks

One task-owned `Pixel_6a` AVD, API 33 x86_64, `emulator-5554`, 1080x2400. No physical
phone was attached. Checks used fresh UI trees, screenshots, and logcat.

- Cold launch and synthetic sample selection succeeded. The hole sample displayed
  4.154 cm² and its automatic overlay retained the interior hole.
- Camera permission denied: explanatory recovery controls appeared. Granting
  permission started actual CameraX frames from the emulator virtual scene.
  Frames without markers showed no area; both Freeze controls were disabled.
- Switching from the camera to Open photo stopped the camera flow. Selecting the
  task's half-circle PNG from Downloads measured 2.996 cm² through the URI import
  path. This is a synthetic QA file imported as a photo; only built-in samples
  receive the app's synthetic flag automatically.
- Review has the automatic overlay, backing selection, sensitivity, sample ID,
  and save controls. Add, erase, undo, reset, and the editing dialog are absent.
- Saving `QA-auto-half` and force-stopping/restarting the app preserved the record
  in Saved. Share opened Android's chooser with the ZIP URI; no external sharing
  destination was selected.
- Read-back of that app-private ZIP verified 299.55625 mm², calibration metadata,
  CSV, source image, rectified image, overlay, and tissue mask. Manual-edit fields
  are absent from both JSON and CSV. Archive writes use a temporary file followed
  by rename.
- Print cutout opened Create Document and successfully saved the matching PDF
  in Downloads. The first immediate read preceded asynchronous completion; the
  completed 6167-byte export was subsequently checked by hash.
- Final LeafArea/AndroidRuntime error log contained no errors.

Evidence lives under `.build-logs/qa/`, including `artifact-audit.json`,
`QA-auto-half.zip`, UI XML/PNG files, and the exported PDF. Reusable QA helpers:
`tools/android-qa.py` and `tools/verify-artifacts.py` (the latter expects the named
QA record and PDF export on the emulator).

## Remaining physical validation

No printed template, actual LI-6800 head fit, real leaf measurement, or physical
phone camera has been tested. Live camera transport and static marker processing
were checked separately; continuous tracking of a physical marked cutout remains
untested. Blue-backing behavior has not received numerical fixture validation.
No claim is made about performance across phones or production release readiness.

The app has no camera lens-distortion model, automatic cut-edge verification, or
leaf recognition model. Shadows, reflections, an incorrect backing setting,
printer scaling, badly cut paper, paper curvature, and leaf/marker plane separation
can bias results even when marker fit is good. Use a flat matte backing, a centered
near-normal view, and inspect the automatic overlay. Establish accuracy with
independently measured shapes, repeated prints, real leaves, and target phones
before relying on results for scientific reporting.

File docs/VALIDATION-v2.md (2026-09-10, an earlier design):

# V2 marker layout / app 0.2.0 - 2026-09-10

The user's field-use screenshot showed the V1 app reporting 3.357 cm² with all
six markers detected and 0.08 mm marker fit residual. This demonstrates one
real-world use case; it supplies no independent ground-truth leaf area.

## Geometry changes

- Ten 8 mm ArUco `DICT_4X4_50` markers, IDs 20-29, replace the six 10 mm V1 markers.
- Eight side markers: x = -42, -18, +8, +24 mm, y = -25 and +25 mm.
- Two markers behind the opening: (-42, 0) and (-24, 0) mm.
- Side wings extend from x=17 to x=31 mm, an increase of 14 mm. Overall dimensions
  are 111 x 68 mm. The central front 90-degree R20 arc, its tip at x=20, and
  the 6 cm² opening remain unchanged. STEP backing thickness stays 0.4 mm.
- Labels and a HOLD HERE area occupy the rear section, away from the opening.

Four or more detected markers are required. Their centers must surround the
opening center, with markers above, below, ahead of, and behind it. A rear-center
marker can replace an obscured side marker. The existing 24-pixel minimum marker
edge, 110-pixel minimum opening span, and fit/sharpness gates are retained.
Smaller markers reduce pixel coverage at a given distance; the app may request
moving closer. Their physical reliability is not yet established.

V1 and V2 use disjoint IDs. The app automatically selects the correct dimensions,
rejects mixed V1/V2 frames, and carries the actual template with each measurement
through resegmentation and archive saving. The status uses the correct total of
6 or 10 markers. The Print cutout action exports V2. V2 prints require app 0.2.0
or newer; V1 prints remain usable. All original PDFs, V1 artifacts, and the V1
app APK are preserved.
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

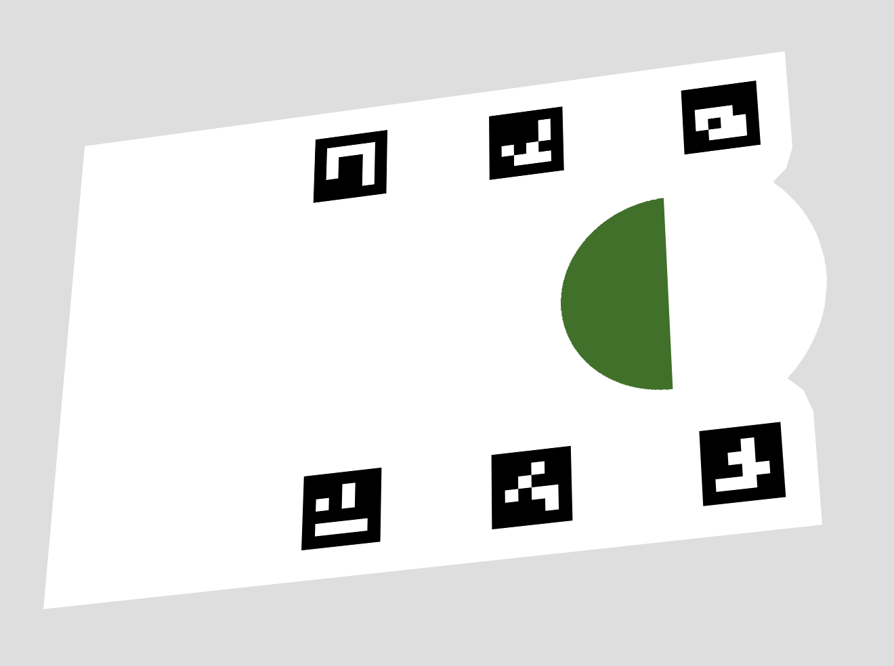
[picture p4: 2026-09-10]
app/src/androidTest/assets/samples-v1/perspective.png

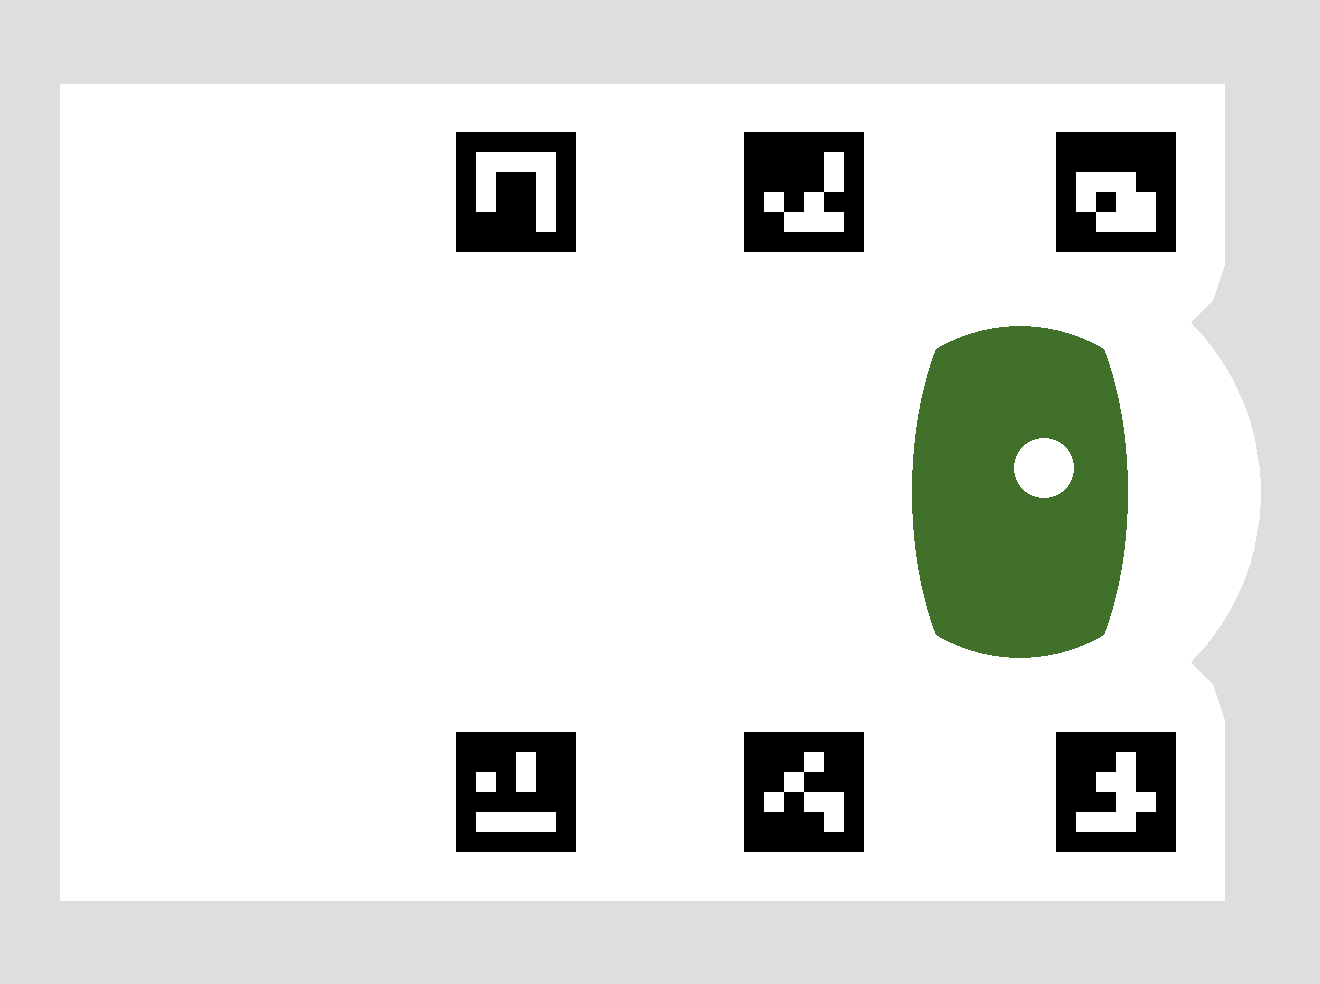
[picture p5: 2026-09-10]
app/src/androidTest/assets/samples-v1/leaf-hole.png

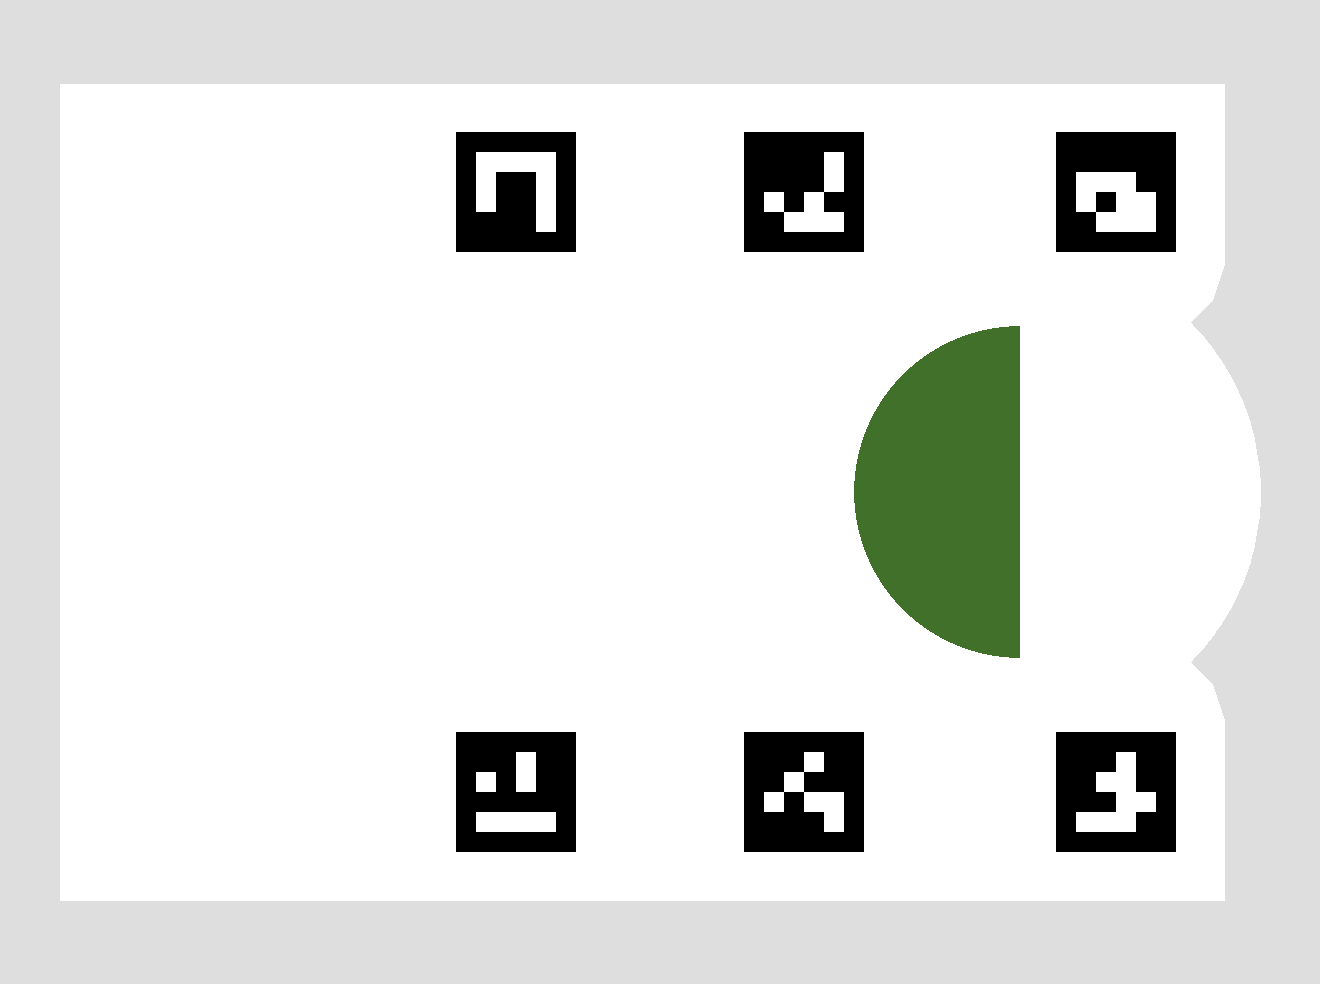
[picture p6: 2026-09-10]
app/src/androidTest/assets/samples-v1/half.png

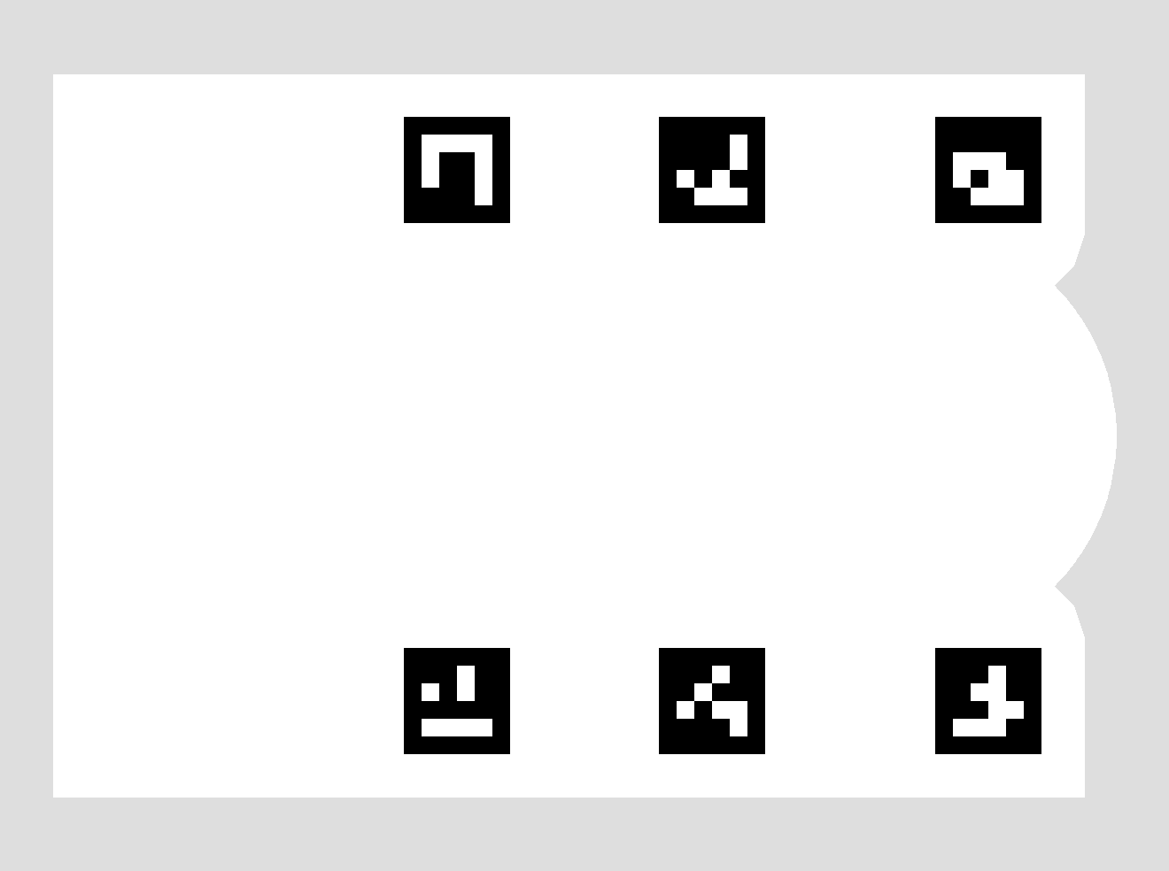
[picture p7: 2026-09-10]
app/src/androidTest/assets/samples-v1/empty.png

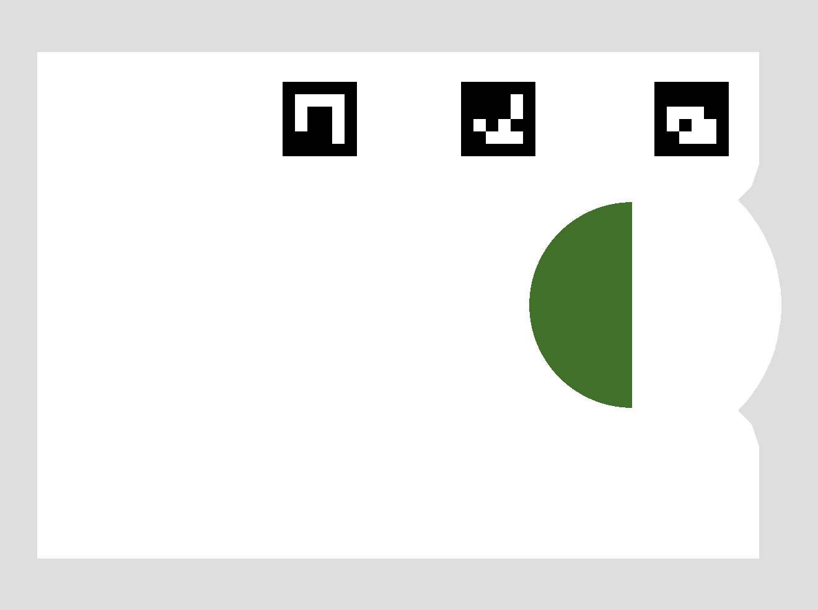
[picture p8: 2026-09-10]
app/src/androidTest/assets/samples-v1/missing-markers.png

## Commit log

2026-09-10 Initial source import for Leaf Area 0.4.0
    [LI6800-6cm2-mask-v2-0.4mm.step]
2026-09-10 Update Leaf Area to 0.4.4
    Remember explicit camera choices and pin physical preview and analysis streams. Add the flashlight toggle, rename Calibration, and center the Save control.
    Simplify the public README and record build, emulator, and release verification.
